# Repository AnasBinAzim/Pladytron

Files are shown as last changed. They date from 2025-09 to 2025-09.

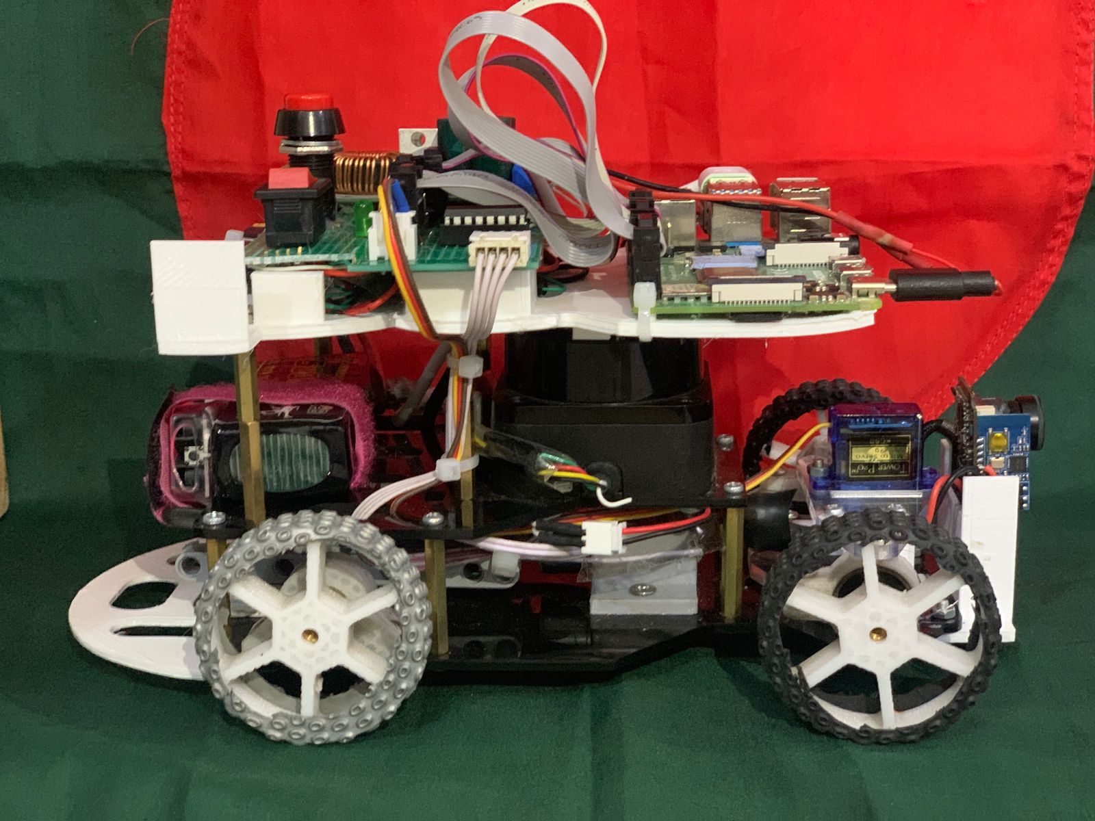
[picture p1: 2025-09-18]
v-photos/rightimage.jpeg

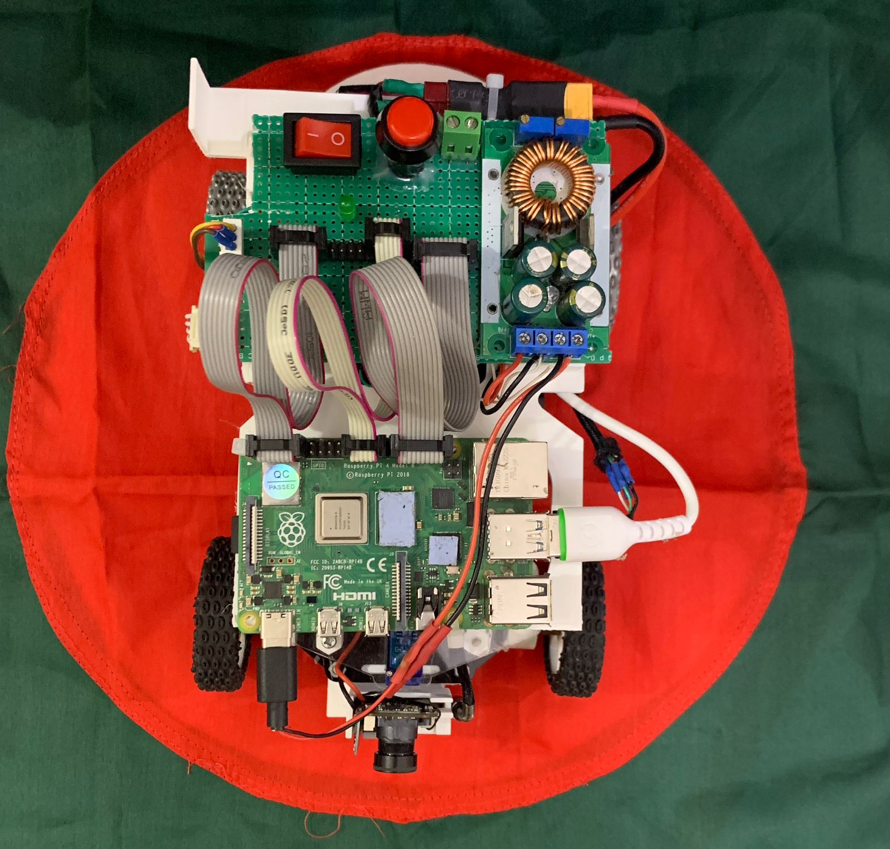
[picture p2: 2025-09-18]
v-photos/topimage.jpeg

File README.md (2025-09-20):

# **🤖 INTRODUCING TEAM PLADYTRON - WRO 2025**
<div align="center">
  

</div>

## 👥 **Team PLADYTRON**

| 👤 Name | 🎓 Institution | 📚 Class/Year | 🎂 Age  |
|---|---|---|---|
| **Anas Bin Azim** | Adamjee Cantonment College | Class XII | 17 |
| **SM Mohiuddin Sami**| Rajuk Uttara Model College | Class XII | 17 |

---

**Team Origin**: Bangladesh

---

## 🏅 Achievements

- 🥇 **Champion, WRO Bangladesh 2024 (Future Engineers)**
- 🌍 20th place **WRO International in Izmir, Turkey**
- 🛠 Multiple national awards in robotics, AI, and competitive programming contests

---

### 🌟 **The Meaning Behind PLADYTRON**

Our team, “PLADYTRON,” is a perfect blend of technology and imagination—think of Ultron if he had a heart (and wasn’t trying to destroy the world). Inspired by the advanced intelligence of Ultron, we aim to create something truly powerful—but with a lot less existential dread and world domination plans. Plady, on the other hand, is our grounding force, a reminder that even in the world of high-tech innovation, we still know how to laugh, learn, and—let's be honest—mess up a few things along the way.
Behind every project, every line of code, there’s an unseen force—kind of like a secret weapon. And that weapon? The unwavering support of those who stand with us. Their belief in us, quietly powering every step, is the real secret sauce to our success. It’s like having a sidekick in a superhero movie, except instead of a cape, they offer advice, encouragement, and the occasional snack.
Pladytron isn’t just a name—it’s the heart and humor of a shared dream. It’s a place where creativity meets technology, and where the unexpected becomes possible. We’re not just building robots or software—we’re building something that (hopefully) makes the world a little better and a lot more fun. After all, even Ultron had a good idea at first, right?

---

# The Team  

## Anas Bin Azim  



**Age:** 17  

**High School:** Adamjee Cantonment College, Dhaka 

**Description:** Hi! I’m Anas from Bangladesh and this is my second WRO International season. In 2024, I had the honor of representing Team Mayerdoa Robotics at the World Robot Olympiad in Turkey, where we proudly placed 20th in the Future Engineers category. I’ve been deeply involved in robotics for over 4 years, building autonomous systems and competing in both national and international competitions. Beyond robotics, I’m passionate about programming, innovation, quizzing, traveling, and playing cricket]  

---

## Mohiuddin Sami  



**Age:** 17  

**High School:** Rajuk Uttara Model College, Dhaka 

**Description:** Hi! I’m Sayed Md. Mohiuddin Sami from Rajuk Uttara Model College. I’ve been part of the BDOI camp for 2 years and have spent the last 2 years working in robotics and WRO. In 2024, I had the chance to represent Bangladesh at the World Robot Olympiad International Finals in Turkey. I’ve also been doing competitive programming for 4 years, which has helped me grow in problem-solving and logical thinking. Outside of robotics and coding, I enjoy quizzing, traveling, and exploring new ideas.

## 🎉 Project Overview
SMOKI

This repository includes all files, designs, and code for **SMOKI**, our WRO 2024 robot. Below is the folder structure:
Here’s a breakdown of the project folders:

---

## 📑 Table of Contents

- [Code](./Code)  
- [Software Setup](./Software-Setup)  
- [WRO 2024 Future Engineers: Self-Driving Project](./WRO-2024-Future-Engineers-Self-Driving...)  
- [Experiments](./experiments)  
- [Model](./model)  
- [Problems and Solutions](./problemsandsolutions)  
- [Schematic](./schematic)  
- [Source (src)](./src)  
- [t-photos](./t-photos)  
- [v-photos](./v-photos)  
- [Video](./video)  
- [README.md](./README.md)  
---

## Robot Photos (All Directions)

<table>
  <tr>
    <td align="center"><b>Front</b></td>
    <td align="center"><b>Back</b></td>
  </tr>
  <tr>
    <td>
</td>
    <td>
</td>
  </tr>
  <tr>
    <td align="center"><b>Top</b></td>
    <td align="center"><b>Bottom</b></td>
  </tr>
  <tr>
    <td>
</td>
    <td>
</td>
  </tr>
  <tr>
    <td align="center"><b>Left</b></td>
    <td align="center"><b>Right</b></td>
  </tr>
  <tr>
    <td>
</td>
    <td>
</td>
  </tr>
</table>

----

---

### Mission Overview for WRO Future Engineers Rounds

<table>
  <tr>
    <td width="50%" valign="top" align="left">
      <h3>🏁 Round 1: Lap Completion</h3>
      <p>In <strong>Round 1</strong>, the robot must autonomously complete <strong>three laps</strong> on a pre-defined track. The goal of this round is for the bot to demonstrate stable navigation and precise lap tracking without any obstacle avoidance requirements.</p>
      <ul>
        <li><strong>Objective</strong>: Complete three laps on the track within the allotted time.</li>
        <li><strong>Key Tasks</strong>: Accurate path-following, speed control, and lap counting.</li>
      </ul>
      <div align="center">
        <br><br><br><br><br>
        Round 1 WRO Track
      </div>
    </td>
    <td width="50%" valign="top" align="left">
      <h3>🏆 Round 2: Lap Completion with Obstacle Avoidance and Parking</h3>
      <p>In <strong>Round 2</strong>, the bot must complete <strong>three laps</strong> while avoiding green and red obstacles:</p>
      <ul>
        <li><strong>Green Obstacles</strong>: The bot should move <strong>left</strong> to avoid.</li>
        <li><strong>Red Obstacles</strong>: The bot should move <strong>right</strong> to avoid.</li>
      </ul>
      <p>After completing the laps, the bot must accurately park within a designated zone.</p>
      <ul>
        <li><strong>Objective</strong>: Complete three laps, avoid obstacles, and park in the designated area.</li>
        <li><strong>Tasks</strong>: Obstacle detection, color-based avoidance, and precision parking.</li>
      </ul>
      <div align="center">
        Round 2 WRO Track
      </div>
    </td>
  </tr>
</table>

---
>[!IMPORTANT]
>**Important: WRO Future Engineers Rulebook**
>* **Thorough Reading:** Ensure that you thoroughly read the **WRO Future Engineers 2024 Rulebook** to understand all rules and guidelines.
>* **Official Link:** Access the rulebook here: [🔗 WRO Future Engineers 2024 Rulebook](https://wro-association.org/competitions/future-engineers/).

---
---

## 🧩 Components and Hardware
Our bot is equipped with various components that support its autonomous functionality. Here is a breakdown of the key hardware elements used in this project:

| Component | Description | Image | Purchase Link |
|---|---|---|---|
| **Chassis - Custom Made** | Custom-designed chassis tailored to fit all components and optimize stability and movement. |  | N/A |
| **RPLIDAR C1** | 360-degree laser scanner used for mapping and obstacle detection. |  | [Purchase RPLIDAR C1](https://www.mybotshop.de/SLAMTEC-RPLIDAR-C1-360-Laser-Scanner-12-m) |
| **Servo Motor SG90** | Small, lightweight servo motor used for precise control of angles and positioning. |  | [Purchase SG90](https://bongotech.ai/product/sg90-micro-servo-motor-180-degree) |
| **SJ CAM C200** | Captures visual data, supporting navigation and obstacle detection tasks. |  | [Purchase SJ CAM C200](https://amzn.to/3SJCAM) (From previous knowledge) |
| **Buck Module XL4016** | Provides stable voltage regulation for power management. |  | [Purchase XL4016](https://amzn.to/4xl4016) (From previous knowledge) |
| **Motor Driver L293D** | Dual H-Bridge motor driver for controlling DC motors and stepper motors. |  | [Purchase L293D](https://electropeak.com/l293d-motor-drive-shield) |
| **Booster Module 5V to 40V** | Voltage booster module to step up power supply from 5V to 40V, supporting high-voltage requirements. |  | [Purchase Booster Module](https://robu.in/product-category/electronic-modules/electronic-module/buck-boost-converter/boost-converter/) |

# Mobility Management :

#### 🛠️ Chassis Assembly Process

## CHASSIS FIRST FLOOR : 



This is the first floor of the robot chassis, designed to serve as the primary structural layer of the bot. The STL model shows a flat base plate with multiple precisely positioned mounting holes and slots for components.

Key Features:

Steering Shaft Mount: The elongated slot at the top center is designed to hold the steering shaft, ensuring smooth and stable movement.

Servo Motor Mount: Dedicated mounting holes allow the servo motor to be securely attached for steering control.

Camera Holder: The central cut-out and surrounding structure provide space for installing a camera for vision-based navigation.

Wheel Mounts: Side holes are aligned to support the wheels, making them properly fixed to the frame.

Base Support: This floor acts as the foundation of the robot, supporting the upper floors and ensuring stability during operation.

Dimensions:

Width (X): 101.5 mm

Length (Y): 185.0 mm

Thickness (Z): 10.0 mm

---
---

### CHASSIS STEERING :


This is the steering plate of the robot chassis, designed to integrate with the first floor and provide precise steering control. The central rectangular gap is a servo clearance slot, which allows the servo horn and linkage to move freely during steering. The smaller holes around the center are meant for mounting the servo securely, while the larger side holes provide attachment points to connect the steering plate with the rest of the chassis. The plate is compact yet durable, ensuring stability during turns, and it directly connects the servo motor to the steering shaft and wheels, making it an essential component for controlling the robot’s movement.

Dimensions:

Width (X): 96.2 mm

Height (Y): 35.55 mm

Thickness (Z): 10 mm

---
---

### STEERING SHAFT :



This part is the steering shaft of the robot chassis. It connects directly to the steering plate and transmits the motion from the servo motor to the wheels, enabling controlled directional movement. The design includes a central body with mounting cut-outs and side holes that allow it to be fixed securely to the chassis while maintaining free rotational movement where needed. Its sturdy build ensures that torque from the servo is effectively transferred to the wheels without bending or slipping, making it a key component for precise steering.

Dimensions:

Width (X): 

Height (Y): 

Thickness (Z): 

---
---

## CHASSIS SECOND FLOOR :


This is the second floor of the robot chassis, designed to mount the following components:

RPLIDAR C1 (with a 10 cm clearance ensured by floor orientation)

LiPo 1500mAh 9A 3S battery

STL Dimensions: 131.27 mm × 101.50 mm × 10.00 mm

The plate includes cutouts for weight reduction and cable management, along with mounting holes for secure installation. Its orientation was carefully adjusted to provide the RPLIDAR with optimal clearance for unobstructed 360° scanning.

---

## CHASSIS TOP FLOOR:


Top & 3rd Floor – Electronics Section

This floor of the chassis holds the core electronic components required for power regulation and motor control.

Components

Raspberry Pi 4B – Acts as the main controller, handling computation, control logic, and communication.

XL4016 Buck Converter – Steps down the LiPo battery voltage to the levels required by the Raspberry Pi and other electronics.

L293D Motor Driver – Provides motor control by supplying the necessary current and voltage to the DC motors.

Power Switch – Allows safe shutdown and startup of the electronics.

Veroboard – Serves as the wiring platform, connecting the Raspberry Pi, buck converter, motor driver, and switch.

Functionality

The LiPo battery powers the system.

The buck converter regulates the voltage for stable Raspberry Pi operation.

The L293D motor driver interfaces between the Raspberry Pi and the motors, enabling directional control.

The veroboard ensures secure and organized wiring between all components.

The switch provides overall power control for the floor.

---
---

>[!IMPORTANT]
> ALL THE STL AND DXF FILES ARE PROVIDED IN THE MODEL SECTION AND A PREVIEW OF THE WHOLE THING COMBINED IS GIVEN BELOW.
---

# TOTAL PREVIEW:

## Model Views

<table>
  <tr>
    <td align="center"><b>Top</b></td>
    <td align="center"><b>Bottom</b></td>
  </tr>
  <tr>
    <td>rsz_iwo

</td>
    <td>bottomviewbot
</td>
  </tr>
  <tr>
    <td align="center"><b>Left</b></td>
    <td align="center"><b>Right</b></td>
  </tr>
  <tr>
    <td>leftviewbot
</td>
    <td>rightviewbot
</td>
<tr>
    <td align="center"><b>Tilt1</b></td>
    <td align="center"><b>Tilt2</b></td>
  </tr>
  <tr>
    <td>TILTEDIMAGE
</td>
    <td>TILTEDIMAGE

</td>
  </tr>

</table>

---
---

# Mobility Management:

The mobility system of our robot has been meticulously designed to ensure smooth, efficient, and reliable movement, addressing both power distribution and maneuverability. This section outlines the evolution of our robot's mobility systems, including upgrades to the steering and gear systems.

---

#### **16GA 800 RPM DC Gear Motor**

<table>
<tr>
<td width="50%">
<div align="center">
  

</div>
</td>
<td width="50%">

A **16GA DC gear motor** is a DC motor with an integrated gearbox. It provides controlled shaft rotation with increased output torque through gearbox reduction.

##### **How the Motor Works**
- The DC motor converts electrical input into rotational motion of the armature and shaft.  
- The gearbox stages reduce output speed and increase torque at the output shaft.  
- The D-flat on the shaft provides a positive mechanical interface for gears, pulleys, or couplings.

##### **Specifications**
- **Rated Speed:** 800 RPM  
- **Shaft Diameter:** 3.0 mm (D-flat: 2.5 mm)  
- **Gearbox Diameter:** 16 mm  
- **Gearbox Length:** 14 mm  
- **Motor Body Length:** 26.5 mm  
- **Shaft Length (protruding):** 11.2 mm

##### **Advantages**
1. **Compact Design**: Small gearbox diameter and short overall length for tight assemblies.  
2. **Increased Torque**: Gear reduction delivers higher torque at the output shaft for loaded conditions.  
3. **Positive Shaft Interface**: D-flat prevents rotary slip when fitted with set-screws or couplings.

</td>
</tr>
</table>

---

### **Rear Axle Power Distribution**

Initially, the rear wheels were powered through a **Bevel Gear**, but we later upgraded to a **Differential Gearbox** to improve efficiency and performance during turns.

---

#### **Bevel Gear**

<table>
<tr>
<td width="50%">
<div align="center">
  
</div>
</td>
<td width="50%">

A **bevel gear** is a type of gear where the axes of the two shafts intersect, and the tooth-bearing faces of the gears are conical. Bevel gears are commonly used to transfer motion between intersecting shafts at an angle, typically 90°.

##### **How Bevel Gears Work**
- A driver gear transfers motion to a driven gear, which rotates an output shaft.
- The teeth of the gears are designed to mesh smoothly, transferring torque efficiently between the shafts.

##### **Advantages of Bevel Gears**
1. **Compact Design**: Suitable for space-constrained applications.
2. **Efficient Torque Transfer**: Provides reliable power transmission at angles.
3. **Versatility**: Can operate at angles other than 90° if needed.

</td>
</tr>
</table>

---
>[!IMPORTANT]
> Bevel gears were essential in the initial stages of our design, but they had limitations in terms of energy efficiency during turns.
---

#### **Differential Gearbox**

<table>
<tr>
<td width="50%">

A **differential gearbox** allows the wheels on the same axle to rotate at different speeds while receiving power from a single motor. This is crucial for smooth turning, where the outer wheel must travel a larger distance than the inner wheel.

##### **Advantages of Differential Gearbox**
1. **Smooth Turns**: Adapts to varying wheel speeds, ensuring efficient cornering.
2. **Energy Efficiency**: Reduces energy wastage by minimizing wheel slippage.
3. **Component Longevity**: Minimizes wear on tires and axles.

##### **How Differential Gears Work**
- Power from the motor is delivered to an input shaft.
- The differential splits the torque between the two wheels via bevel or spider gears inside the housing.
- During turns, the differential allows one wheel to spin faster than the other, ensuring smooth movement.

</td>
<td width="50%">
<div align="center">
  
</div>
</td>
</tr>
</table>

---

### **Servo Motor with L293D Motor Driver**

<table>
<tr>
<td width="30%">
<div align="center">
  
</div>
</td>
<td width="70%">

We used the **L293D Motor Driver** in combination with a **Servo Motor** to control the robot's wheels effectively. The L293D is a dual H-Bridge motor driver that is perfectly suited for the LEGO motor, which operates at **750mA** current.

##### **Why L293D?**
- **Optimal Current Capacity**: Can handle up to **1A** peak current, suitable for the LEGO motor’s 750mA requirement.
- **Bidirectional Control**: Facilitates forward and backward motion of the wheels.
- **Compact and Lightweight**: Ideal for small-scale robotic systems.
- **PWM Support**: Enables smooth speed control of the motors.

##### **Advantages of the Servo Motor with L293D**
1. **Accurate Steering**: The servo motor ensures precise angle adjustments.
2. **Smooth Speed Control**: PWM functionality provides variable speed control.
3. **Efficient Current Management**: Matches the LEGO motor's current needs, ensuring reliable operation.

</td>
</tr>
</table>

---

#### **Comparison: Bevel Gear vs. Differential Gearbox**

| **Feature** | **Bevel Gear** | **Differential Gearbox** |
|---|---|---|
| **Turning Efficiency** | Limited; fixed wheel speeds. | Superior; wheels rotate independently. |
| **Energy Usage** | Higher due to slippage during turns. | Lower; optimized for dynamic turns. |
| **Durability** | Higher strain on components. | Reduced strain; longer component life. |

---

### **Steering Systems**

The robot was first designed with an Ackermann Steering System, which is widely recognized for its efficiency in full-scale vehicles where smooth and realistic cornering is important. This system was chosen because it closely replicates how cars steer, making it ideal for projects that aim to simulate real-world vehicle dynamics. However, as the design of the robot progressed, the steering system was later replaced with a LEGO-based steering mechanism. The change was made to simplify construction, reduce complexity, and improve modularity, all while maintaining effective and reliable steering control. The LEGO steering setup makes it easier to experiment, repair, and scale the design without sacrificing too much performance, which is an important advantage in prototyping and educational robotics.

The Ackermann Steering System itself is a clever mechanical arrangement that ensures each wheel follows a natural path while the vehicle turns. In any cornering situation, the inner wheels of a vehicle must rotate at a sharper angle than the outer wheels because they travel along a smaller radius. Without this adjustment, wheels would slip or drag, leading to wasted energy and uneven motion. The Ackermann geometry solves this by connecting the front wheels through steering arms angled in such a way that the imaginary extension of these arms intersects at the center of the turn’s radius. This alignment ensures that all wheels follow concentric paths, allowing the vehicle to turn smoothly and efficiently without excessive tire wear or unnecessary power loss.

In practice, the Ackermann system has several clear advantages for robotic applications. It minimizes slippage between the wheels and the ground, which results in more efficient turning and better energy conservation. The reduction of wheel drag also means that the motors driving the vehicle consume less power during maneuvers, which is especially valuable in battery-powered robots where energy efficiency extends operating time. Another key benefit is that it provides a highly realistic simulation of how cars steer, making it particularly useful for robotics projects that aim to mimic real-world automotive systems or serve as educational platforms to demonstrate fundamental vehicle dynamics. Although our project ultimately transitioned to a LEGO-based steering approach for modularity and ease of construction, the principles and advantages of Ackermann steering remain highly relevant for anyone interested in understanding efficient and practical steering systems in robotics and beyond.

---
---

## **SERVO MOTOR :** 
# Servo Motor - Tower Pro MG90S

<table>
  <tr>
    <td>
      
    </td>
    <td>
      <h3>Specifications</h3>
      <ul>
        <li><strong>Weight:</strong> 13.4g</li>
        <li><strong>Stall torque:</strong> 2.2 kgf·cm (6V)</li>
        <li><strong>Operating speed:</strong> 0.08 s/60° (6V)</li>
        <li><strong>Rotation angle:</strong> 120°</li>
        <li><strong>Gear type:</strong> Metal gears</li>
        <li><strong>Operating voltage:</strong> 4.8V – 6V</li>
      </ul>
    </td>
  </tr>
</table>

---

The Tower Pro MG90S is a micro servo motor designed for applications where compact size and high torque are required, making it a reliable choice for robotics, RC models, and automation projects. Built with durable metal gears, it offers a longer operational lifespan compared to plastic-geared alternatives, while maintaining a lightweight 13.4g profile that makes it easy to integrate into small-scale designs. Operating on a voltage range of 4.8V to 6V, it delivers up to 2.2 kgf·cm stall torque and a quick 0.08s/60° response at 6V, ensuring both strength and speed for demanding tasks. With a rotation range of 120°, the MG90S provides precise angular control suitable for robotic arms, pan-tilt camera gimbals, or steering systems in miniature vehicles. Its compatibility with standard PWM signals means it can be driven directly by most microcontrollers, including Arduino and Raspberry Pi, without the need for additional hardware. Engineers and hobbyists often choose the MG90S because it balances performance and durability in a very small form factor, making it a practical and cost-effective solution for projects that require accurate movement and dependable performance under continuous load.

---

## Where to Buy

You can purchase the servo motor here:  
👉 [Tower Pro MG90S - Cleste.ro](https://cleste.ro/motor-servo-mg90s-180g.html)

## SERVO-HOLDER :



### SG90 / MG90 Servo Holder

This is a **servo motor holder/mount** designed for **SG90** and **MG90S micro servos**.  
It provides a secure and stable way to fix the servo motor onto different surfaces such as a robot chassis, acrylic base, or wooden frame.

---

## Description
## Servo Motor Holder / Mount (SG90 & MG90S)

This servo motor holder is designed specifically for the popular SG90 and MG90S micro servos, providing a secure and reliable way to mount the motor onto different surfaces such as a robot chassis, acrylic base, or even wooden frames. The primary goal of the mount is to eliminate instability and vibration, ensuring that the servo can deliver accurate and repeatable movements during operation. For small-scale robotics and automation projects where precision matters, this holder becomes an essential accessory.
The base of the mount is a flat rectangular plate equipped with four mounting holes that allow it to be firmly attached using screws or bolts. This rigid foundation ensures that once the holder is installed, it remains stable and does not shift under load, even when the servo is driving linkages or mechanical arms. At the center of the design, there is a servo housing slot carefully dimensioned to snugly fit SG90 and MG90S servos. This slot prevents any side-to-side play and keeps the servo perfectly aligned, which is important when the servo is used for steering mechanisms, grippers, or robotic arms where accuracy of angular motion is critical.
On the sides of the housing are clamp sections with additional screw holes, which allow the servo to be tightly locked in place once inserted. This design makes sure the servo remains fixed during continuous operation, preventing unwanted movement that could lead to mechanical inaccuracy or wear. At the front, the mount features an open clearance space that allows the servo horn or arm to rotate freely without obstruction. This ensures that the servo’s full range of motion can be utilized, whether it is controlling wheels, levers, or pan-tilt systems.

The bottom of the mount is left open to provide space for the servo’s wiring to pass through. This prevents cable bending and stress at the connector, reducing the risk of damage to the wires over time and allowing easy integration into compact robotic builds. By providing both mechanical stability and practical cable management, the holder is designed to extend the lifespan of the servo and improve overall reliability of the system.

In terms of material, PLA is often sufficient for hobby projects where light loads and indoor conditions are expected. However, for applications requiring greater durability or exposure to outdoor environments, PETG or ABS is recommended since both materials offer improved toughness and resistance to stress compared to PLA. The mount’s design is fully compatible with Tower Pro SG90 and MG90S servos, making it versatile for use across a wide range of robotic and automation projects where these micro servos are commonly deployed.

---
---
# ⚡ Power and Sense Management

The **Power and Sense Management** system of our robot has been meticulously designed to optimize performance while ensuring reliable power delivery, precise sensing, and efficient communication between components.
# Battery: Gens Ace Airsoft 3S Li-Po Battery (11.1V 1500mAh 35C)

<table>
  <tr>
    <td>
      
    </td>
    <td>
      <h3>Specifications</h3>
      <ul>
        <li><strong>Brand:</strong> Gens Ace Airsoft</li>
        <li><strong>Battery Type:</strong> Li-Po (Lithium Polymer)</li>
        <li><strong>Nominal Voltage:</strong> 11.1V (3S)</li>
        <li><strong>Capacity:</strong> 1500 mAh</li>
        <li><strong>Energy:</strong> 16.65 Wh</li>
        <li><strong>Discharge Rate:</strong> 35C</li>
        <li><strong>Connector Type:</strong> T-Plug / Deans Connector</li>
        <li><strong>Balance Plug:</strong> JST-XH</li>
        <li><strong>Weight:</strong> ~120g</li>
      </ul>
    </td>
  </tr>
</table>

---

The **Gens Ace 3S Li-Po battery** is a lightweight and powerful energy source designed for high-performance robotics, drones, RC vehicles, and airsoft equipment.  
With a **capacity of 1500mAh** and a **35C discharge rating**, it delivers consistent current output suitable for motors, sensors, and controllers that require stable power.  
Its **compact size and low weight** make it easy to integrate into mobile robotic platforms.  
The built-in **Deans/T-Plug connector** ensures low-resistance power delivery, while the **JST-XH balance connector** allows for safe charging and cell balancing.  

This battery is ideal for applications requiring **high burst currents, reliability, and long cycle life**, making it a solid choice for powering small-to-medium robotics systems.

---

# **Microcontroller :**  
# Raspberry Pi 4 Model B

<table>
  <tr>
    <td>
      
    </td>
    <td>
      <h3>Specifications</h3>
      <ul>
        <li><strong>Processor:</strong> Broadcom BCM2711, Quad-core Cortex-A72 (ARM v8) 64-bit SoC @ 1.5GHz</li>
        <li><strong>RAM Options:</strong> 2GB, 4GB, or 8GB LPDDR4-3200 SDRAM</li>
        <li><strong>Networking:</strong> Gigabit Ethernet, 2.4GHz & 5.0GHz 802.11ac Wi-Fi, Bluetooth 5.0</li>
        <li><strong>USB Ports:</strong> 2 × USB 3.0, 2 × USB 2.0</li>
        <li><strong>Video & Sound:</strong> 2 × micro-HDMI ports (up to 4Kp60), MIPI DSI display port, MIPI CSI camera port</li>
        <li><strong>Storage:</strong> microSD card slot for OS and data storage</li>
        <li><strong>GPIO:</strong> 40-pin header, backward-compatible with previous Raspberry Pi boards</li>
        <li><strong>Power:</strong> 5V DC via USB-C connector (minimum 3A)</li>
        <li><strong>Dimensions:</strong> 85.6mm × 56.5mm</li>
      </ul>
    </td>
  </tr>
</table>

---

The **Raspberry Pi 4 Model B** is a powerful single-board computer that serves as the main controller of the robot.  
It offers significant improvements over previous models, including a faster **quad-core ARM Cortex-A72 CPU**, more memory options, dual micro-HDMI outputs supporting **dual 4K displays**, and faster networking with **true Gigabit Ethernet** and **dual-band Wi-Fi**.  
Its 40-pin GPIO header provides compatibility with a wide range of sensors, motor drivers, and other modules, making it extremely versatile for robotics and IoT applications.  

Thanks to its **USB 3.0 ports**, it can interface with high-speed peripherals such as cameras, LIDAR sensors, or external storage, while the **USB-C power input** ensures stable operation.  
In this project, the Raspberry Pi 4B acts as the **central brain**, handling computer vision, path planning, and high-level decision-making, while coordinating with microcontrollers, sensors, and actuators to control the entire robot.

---

## **GPIO PINOUT OF RPI 4B** : 

# Raspberry Pi 4 Model B GPIO (40-pin Header)

<table>
  <tr>
    <td>
      
    </td>
    <td>
      <h3>Specifications</h3>
      <ul>
        <li><strong>Total Pins:</strong> 40 (2×20 header)</li>
        <li><strong>Power Pins:</strong> 2 × 5V, 2 × 3.3V, 8 × Ground (GND)</li>
        <li><strong>GPIO Pins:</strong> 26 (configurable as input/output)</li>
        <li><strong>Dedicated Interfaces:</strong> 
          <ul>
            <li>UART (TXD, RXD)</li>
            <li>SPI (MOSI, MISO, SCLK, CE0, CE1)</li>
            <li>I²C (SDA, SCL)</li>
            <li>PWM channels</li>
          </ul>
        </li>
        <li><strong>Voltage Levels:</strong> 3.3V logic (NOT 5V-tolerant)</li>
        <li><strong>Backward Compatibility:</strong> Same pinout as Raspberry Pi 3B/3B+</li>
      </ul>
    </td>
  </tr>
</table>

---

The **Raspberry Pi 4B GPIO header** provides 40 pins that allow direct hardware interfacing with sensors, actuators, and external modules.  
Among these are multiple **power pins (5V and 3.3V)**, **ground pins**, and **26 flexible GPIO pins** which can be programmed as input or output using libraries such as **RPi.GPIO** or **GPIO Zero**.  

The header also exposes dedicated hardware interfaces, including **UART for serial communication**, **SPI for high-speed device connections**, and **I²C for multi-sensor integration**, along with PWM support for driving **motors, LEDs, and servos**.  

Because the pins operate at **3.3V logic levels**, external level shifters are required when interfacing with 5V components.  
This GPIO header is the bridge between the Raspberry Pi and the physical world, making it an essential feature for robotics, IoT, and embedded system projects.

---
---

## **BUCK CONVERTER** (8.4 TO 5V) : 
### XL4016 DC-DC Step-Down Module

<table>
  <tr>
    <td>
      
    </td>
    <td>
      <h3>Specifications</h3>
      <ul>
        <li><strong>Chipset:</strong> XL4016E1 DC-DC Buck Converter</li>
        <li><strong>Input Voltage:</strong> 8V – 36V DC</li>
        <li><strong>Output Voltage:</strong> 1.25V – 32V DC (adjustable)</li>
        <li><strong>Output Current:</strong> Up to 8A (continuous), 12A peak</li>
        <li><strong>Conversion Efficiency:</strong> Up to 95%</li>
        <li><strong>Switching Frequency:</strong> ~180 kHz</li>
        <li><strong>Protections:</strong> Over-current, thermal shutdown</li>
        <li><strong>Heat Dissipation:</strong> Integrated heatsink for stability under high load</li>
        <li><strong>Dimensions:</strong> 60mm × 52mm × 20mm (approx.)</li>
      </ul>
    </td>
  </tr>
</table>

---

The **XL4016 buck converter** is a high-power DC–DC step-down module designed to provide stable and efficient voltage regulation for robotics, automation, and embedded systems. With an input range of 8–36V and an adjustable output from 1.25–32V, it is highly versatile and can power a wide variety of subsystems from a single battery source. Its ability to deliver up to **8A of continuous current** (with peaks of 12A) makes it suitable for driving motor controllers, Raspberry Pi boards, and other current-hungry electronics simultaneously. The module achieves up to 95% efficiency, reducing energy losses and minimizing heat buildup. The integrated heatsink ensures stable operation even under heavy loads, while built-in protection circuits safeguard against over-current and thermal issues. For robotics applications, the XL4016 is often recommended because it allows a single Li-Po or Li-ion battery pack to be safely stepped down to multiple regulated voltages, ensuring reliable operation of both logic-level electronics and power-hungry actuators.

---

## **Sensor :**  
# MPU-6050 6-Axis Gyroscope and Accelerometer

<table>
  <tr>
    <td>
      
    </td>
    <td>
      <h3>Specifications</h3>
      <ul>
        <li><strong>Chipset:</strong> InvenSense MPU-6050</li>
        <li><strong>Sensor Type:</strong> 3-axis gyroscope + 3-axis accelerometer</li>
        <li><strong>Operating Voltage:</strong> 3V – 5V</li>
        <li><strong>Communication Interface:</strong> I²C (default address 0x68)</li>
        <li><strong>Gyroscope Range:</strong> ±250, ±500, ±1000, ±2000 °/s</li>
        <li><strong>Accelerometer Range:</strong> ±2g, ±4g, ±8g, ±16g</li>
        <li><strong>Sampling Rate:</strong> Up to 1 kHz</li>
        <li><strong>Digital Motion Processor (DMP):</strong> Built-in for sensor fusion</li>
        <li><strong>Dimensions:</strong> ~20mm × 15mm × 2mm (module size varies)</li>
      </ul>
    </td>
  </tr>
</table>

---

The **MPU-6050** is a 6-axis motion tracking sensor that integrates a **3-axis gyroscope** and a **3-axis accelerometer** on a single chip, making it one of the most widely used sensors in robotics and embedded systems. It communicates via the I²C protocol, which allows it to connect easily to microcontrollers like the Arduino, ESP32, or Raspberry Pi. The sensor provides motion data across multiple selectable ranges, with gyroscope sensitivity from ±250 to ±2000 degrees per second and accelerometer ranges from ±2g to ±16g. This versatility makes it suitable for detecting orientation, angular velocity, and linear acceleration in real time. The built-in **Digital Motion Processor (DMP)** can handle sensor fusion internally, combining gyro and accelerometer data to output stable orientation values, reducing the computational load on the main controller. For robotics, the MPU-6050 is commonly used in balancing robots, drones, navigation systems, and motion-controlled projects, where accurate and responsive motion sensing is essential for stability and control.

---

## **Camera :**  
# SJCAM C200 Action Camera

<table>
  <tr>
    <td>
      
    </td>
    <td>
      <h3>Specifications</h3>
      <ul>
        <li><strong>Sensor:</strong> 4K CMOS image sensor</li>
        <li><strong>Video Resolution:</strong> 4K @ 24fps, 2K @ 30fps, 1080p @ 60fps</li>
        <li><strong>Photo Resolution:</strong> Up to 16MP</li>
        <li><strong>Lens:</strong> 154° wide-angle lens</li>
        <li><strong>Display:</strong> 1.3-inch front screen + status indicators</li>
        <li><strong>Battery:</strong> 1200mAh (removable, USB-C charging)</li>
        <li><strong>Connectivity:</strong> Wi-Fi, USB-C</li>
        <li><strong>Storage:</strong> MicroSD card up to 128GB</li>
        <li><strong>Waterproof:</strong> Up to 5m without case, 30m with case</li>
        <li><strong>Dimensions:</strong> ~68mm × 32mm × 26mm</li>
      </ul>
    </td>
  </tr>
</table>

---

The **SJCAM C200** is a compact 4K action camera designed for high-quality video and photo capture in robotics, drones, and field-testing environments. It features a **154° wide-angle lens**, making it well-suited for wide field-of-view applications such as navigation, mapping, and vision-based obstacle detection. The camera supports recording at multiple resolutions, including **4K at 24fps** and **1080p at 60fps**, giving flexibility between image detail and frame rate depending on the task. With a removable **1200mAh battery** and **USB-C charging**, it provides convenient power management, while Wi-Fi connectivity allows real-time preview and data transfer to companion devices. Its rugged design makes it waterproof up to 5m without housing and up to 30m with an additional case, ensuring reliable performance in outdoor and challenging environments. For robotics projects, the SJCAM C200 is an excellent choice as a vision module, balancing portability, durability, and high-definition imaging in a small and versatile package.
---
---

# *PCB*  
## Previous PCB Design and Power Distribution  

| **Top View of PCB** | **Bottom View of PCB** | **Power Management Diagram** |
|---|---|---|
|  |  |  |

---

The PCB shown above was designed as the **central power management and distribution unit** for the robot, ensuring that every subsystem received the correct voltage and current for stable operation. The board draws power from two **Lithium-Ion cells**, each rated at 4.2V, providing a combined supply of **8.4V** when fully charged. This input is then carefully regulated using multiple DC–DC converters to meet the diverse requirements of the system.  

At the heart of the regulation stage, an **XL4016 buck converter** steps the 8.4V battery voltage down to a stable **5V rail**, which powers the **Raspberry Pi 5** and other core electronics. Additional buck converter modules are integrated to provide subsystem-specific voltages: one module regulates to **6V for the servo motor**, while another supplies **5V dedicated to the ESP32 microcontroller**, ensuring isolation and consistent operation. For the high-power motors, the PCB incorporates a **buck-boost converter** that outputs **12V**, guaranteeing reliable torque and speed even as the battery voltage drops during operation.  

This combination of regulated rails allows the robot to operate multiple controllers, sensors, and actuators from a single compact PCB without instability or power loss. By integrating switching converters and carefully routing the distribution, the board minimizes heat, maximizes efficiency, and protects sensitive comp
onents from voltage fluctuations. Overall, this design highlights the importance of structured power management in robotics, where both logic-level devices and power-hungry actuators must coexist seamlessly on the same platform.

---
# *CurrentPCB* :


Compared to our earlier design, the new PCB introduces several improvements aimed at stability, modularity, and ease of use. The earlier version primarily served as a basic power distribution board with buck converters and minimal control features. In this revised version, additional attention has been given to **structured wiring via ribbon connectors**, improved **switching and manual control through a larger rocker and push button**, and **better integration of the buck converter section** with heat dissipation. The placement of capacitors, inductor coil, and screw terminals has been optimized for cleaner power flow, and the routing now reduces noise and voltage drops across the board. Overall, the new design is more robust, reliable, and serviceable compared to the prototype.  

# *CIRCUITDIAGRAM* :


# Explanation:

This circuit integrates the Raspberry Pi GPIO header with a set of sensors, actuators, and motor driver modules, forming the control and power distribution system for a small robot. The Raspberry Pi acts as the central controller, sending signals to motors, servos, and indicators while also receiving sensor feedback to make decisions in real time.
At the top of the diagram, we see the Raspberry Pi GPIO pinout, which is the core interface between the Pi and external devices. Each pin can be configured as an input or output, supplying logic-level signals (3.3V) that control the connected hardware. The Pi provides 5V and 3.3V power rails, as well as ground connections, which are distributed to all modules in the circuit.
A servo motor is connected to the Pi using three wires: VCC (power), GND (ground), and the SIGNAL pin, which is linked to one of the Pi’s PWM-enabled GPIO pins. This allows the Pi to control the servo angle precisely using PWM (Pulse Width Modulation). Servos are typically used for steering mechanisms or angular adjustments in robots, so this one is likely managing the robot’s front wheel alignment or a pan/tilt system.
On the left side of the circuit, a push button and an LED are wired into the GPIO header. The push button is used as a digital input — when pressed, it connects the GPIO pin to ground, sending a low signal to the Pi. This can be used for resets, mode changes, or manual overrides. The LED, on the other hand, is controlled through a GPIO pin as an output. It provides visual feedback, such as power status, errors, or activity indicators, allowing the operator to easily monitor the robot’s state.
At the bottom, the L293D motor driver IC is connected between the Pi and a DC motor. The Pi itself cannot supply enough current to directly drive motors, so the L293D acts as a buffer and amplifier. It uses the low-current logic signals from the Pi to control the higher-current flow from the battery to the motor. This enables bidirectional motor control (forward and backward rotation) and also supports PWM for speed regulation. In this configuration, the motor shown is most likely one of the drive motors that moves the robot’s wheels.
On the right side, we see an MPU-6050 IMU (Inertial Measurement Unit) connected via I²C communication. The SDA (data) and SCL (clock) lines run from the Pi’s GPIO header to the sensor module, with VCC and GND providing power. The MPU-6050 combines a 3-axis gyroscope and a 3-axis accelerometer, which together measure angular velocity and linear acceleration. This data is essential for balance, orientation, and navigation, particularly in robots that need to track their motion or maintain stability on uneven terrain.
Next to it is a buck converter module (with a heatsink and inductor coil). This component regulates the battery voltage down to safe levels required by the Raspberry Pi, motors, and sensors. Since motors can cause voltage fluctuations when they start or stop, the buck converter ensures that the Pi always receives a clean and stable supply. The input of the buck converter comes directly from the main battery (Li-ion cells), and the outputs are distributed to different subsystems: 5V for the Pi and ESP32, 6V for the servo, and 12V (via buck-boost regulation) for the motors.
The wiring shows how all the power rails (red for positive, black for ground, and green/yellow/orange for signals) are carefully routed to prevent noise and maintain clear separation between logic-level signals and high-current motor wiring. The Pi orchestrates everything: it reads the sensor data from the MPU-6050, processes input from the push button, controls the LED for feedback, drives the servo motor with PWM, and commands the DC motor through the L293D motor driver.

---
# *SCHEMATIC FOR THE NERDS* : 


###  Camera Placement and Functionality

The robot's main camera is positioned at the top and angled slightly downwards. This setup enhances object detection capabilities by providing:
- **🔍 Close-Range Detection**: The camera can identify objects in close proximity with high accuracy.
- **🌐 Extended-Range Detection**: Ensures objects further away are detected effectively.

The camera feeds data to the **Raspberry Pi 4**, which processes image recognition algorithms to detect towers and corner lines. The processed data is then transmitted to the **ESP32 microcontroller** for real-time navigation and obstacle avoidance.

---

>[!IMPORTANT]
> **Power Highlights:**
> - The XL4016 Buck Converter ensures stable voltage regulation, critical for protecting the Raspberry Pi and ESP32 microcontroller during operation.
> - Independent buck modules handle the servo motor and ESP32 power needs, optimizing energy usage across all components.

---
---

## Power Regulation and Control PCB

This PCB is a custom-made prototyping board that acts as the main power regulation and control hub of the robot. It integrates a red rocker switch as the primary ON/OFF control, a large red push button for reset or emergency stop functions, and a green LED that indicates when the system is active. Flat ribbon cables connect the board to the Raspberry Pi or Arduino, carrying essential GPIO signals. The lower section features a copper coil, multiple electrolytic capacitors, and MOSFETs/regulators that form a DC–DC converter, ensuring stable power delivery from the battery to different subsystems. Blue trimpots allow precise voltage calibration, while a screw terminal block provides secure connections for input and output wiring. Altogether, this PCB manages distribution, stabilization, and manual control of power, making it a central part of the robot’s electronic system.

PCB Overview

---

#  OBSTACLE MANAGEMENT AND CODE EPXLANATION

In **Round 1**, our robot **SMOKI** must autonomously complete **three laps** on a predefined track without the need for obstacle avoidance. To achieve precise navigation and lap counting, we have developed a robust algorithm that integrates image processing with control systems.

---

###  Algorithm Overview

1. **📸 Image Acquisition**:
   - The robot captures real-time images of the track using its onboard camera.

2. **🎨 Color Space Conversion**:
   - Captured images are converted from the **RGB** color space to the **HSV (Hue, Saturation, Value)** color space.
   - The HSV color space is chosen for its effectiveness in color segmentation, as it is less sensitive to lighting variations.

3. **🔍 Color Segmentation and Orientation Determination**:
   - Using predetermined HSV ranges, the algorithm isolates the **blue** and **orange** line segments on the track.
   - During the first run, the robot checks whether the blue line appears before the orange line or vice versa.
   - **Orientation Determination**:
     - If the blue line comes before the orange line, the robot sets its orientation accordingly.
     - This initial orientation check ensures the robot follows the track in the correct direction.

4. **📏 Line Detection and Lap Counting**:
   - The **Hough Line Transform** method is applied to detect lines within the segmented images.
   - The robot counts the detected lines to keep track of laps.
   - **Lap Completion**:
     - After counting **12 lines** (corresponding to three laps), the robot initiates a predetermined delay and then stops.

5. **⚙️ Position Correction Using PID Control**:
   - Before setting the orientation, a **PID (Proportional-Integral-Derivative) controller** calculates the error.
   - **Error Calculation**:
     - The error is determined by the difference between the distances measured by sensors on the left and right sides of the robot (i.e., `error = left_distance - right_distance` or vice versa).
   - **Distance Maintenance**:
     - If the orientation is **right-based**, the robot maintains a **25 cm** distance from the right side.
     - If the orientation is **left-based**, it maintains a **25 cm** distance from the left side.
   - The PID controller adjusts the robot's steering to minimize the error, helping it stay centered on the track.

---

The process begins with image acquisition and preprocessing, where high-resolution images are captured at regular intervals to provide up-to-date visual data of the track. These images are then converted into the HSV (Hue, Saturation, Value) color space. Unlike RGB, HSV separates brightness from color information, which makes it more effective for thresholding and detecting specific colors under varying lighting conditions.
Once the images are converted, color segmentation is performed. By applying HSV thresholding, the system isolates pixels belonging to the blue and orange ranges. This allows the robot to detect both blue and orange track lines. The sequence of detected colors is also analyzed to establish the robot’s orientation at the start, ensuring it does not misinterpret direction and mistakenly count laps in reverse.
After segmentation, the system proceeds to line detection using the Hough Transform. First, preprocessing methods such as Gaussian blur and Canny edge detection are applied to enhance the visibility of edges in the image. The Hough Line Transform then detects straight lines by mapping points from image space into a parameter space, identifying lines where multiple points converge. Each detected line crossing increments a counter, and lap completion is recognized after twelve line crossings, which correspond to three full laps of both blue and orange lines combined.
To maintain correct alignment on the track, the robot employs a PID (Proportional–Integral–Derivative) control system for position correction. Distance sensors on either side of the robot provide real-time measurements of its relative position. The difference between left and right readings produces an error signal, which the PID controller minimizes. The proportional term reacts to the current error, the integral term compensates for accumulated past errors, and the derivative term predicts future error based on its rate of change. The controller’s output is translated into steering adjustments, keeping the robot centered. Depending on its orientation, the robot may also bias its movement slightly toward the left or right side of the track, ensuring consistent lap recognition and stable navigation.

## 📊 Round 1 Algorithm - Corner Detection Navigation

In Round 1 of the **Future Engineers** category, our robot follows a structured pipeline to complete a lap, detect corners, and terminate correctly at the finish line. The algorithm is designed to balance **robust line tracking** with **precise stopping conditions**.

---
# Explanation of the the first round :
The flowchart represents the logic behind a line-following robot with LIDAR support, where lap counting and orientation checks are integrated into its navigation system. Let’s walk through it in sequence.
1. Start and Image Capture
The process begins at the Start node. The robot immediately moves to capture an image from its camera. This image forms the basis for detecting whether the guiding line (blue or orange track line) is present in the current frame.
2. Checking for Line Detection
After capturing the image, the robot checks: Is a line detected?
If Yes, it proceeds to the orientation check.
If No, the robot relies on LIDAR scanning to infer the path instead.
This dual check ensures that if the camera fails to detect a line (due to noise, occlusion, or lighting issues), the LIDAR system provides redundancy.
3. Line Detected Path
If a line is found, the robot must determine whether its orientation has already been set.
If orientation is set, the system simply increments the line counter (Line Count ++), tracking how many lines have been crossed.
If orientation is not set, the robot fixes its orientation based on the detected color sequence (blue vs. orange) and also increments the line counter. This prevents mistakes in lap counting by ensuring the robot knows which direction it is traveling.
4. Lap Completion Check
Once the line count is updated, the system checks three conditions simultaneously:
LineCount ≥ 12 → meaning the robot has crossed enough lines for three full laps (each lap includes multiple blue/orange crossings).
LastLine > 1500 ms → a time gap condition that prevents double-counting if two detections happen too close together.
FloorDist < 1500 → a distance-based condition to ensure the robot is physically on the track surface and not falsely detecting lines elsewhere.
If all conditions are satisfied, the robot concludes that laps are complete, moves to Stop Bot, and terminates the code.
If not, the system moves to path correction with LIDAR and PID control.
5. No Line Detected Path
If the camera does not detect a line, the robot initiates a LIDAR scan of its surroundings. From this scan, it checks the slope of adjacent lines detected by LIDAR.
If the slope is perpendicular, this indicates the robot has crossed a track line, so the line counter is incremented and lap completion is re-evaluated.
If the slope is not perpendicular, the system assumes the robot is simply navigating without crossing a line and moves to LIDAR-based pathfinding.
This branch ensures the robot doesn’t lose track of lap progress even if the camera fails.
6. Weighted Average Pathfinding with LIDAR
When either:
the lap is not complete, or
no perpendicular crossing is found,
the system falls back to LIDAR-based navigation. Here, the robot uses a weighted average method from LIDAR readings to determine the best safe path forward (e.g., avoiding obstacles and staying centered).
7. PID Steering Correction
Once the best path is determined, the robot applies a PID controller to calculate the precise steering angle.
The error signal is generated from differences in left/right LIDAR (or distance sensor) readings.
The PID controller minimizes this error to keep the robot aligned on track.
8. Continuing Navigation
Finally, the robot applies the PID steering adjustment and continues navigating along the track until it loops back to capture the next image, repeating the cycle until the termination condition is met.
---
**Flowchart:**

```mermaid
flowchart TD
    A[Start] --> B[Capture Image]
    B --> C{Line Detected?}
    
    %% Line Detected Branch
    C -->|Yes| D{Orientation Set?}
    D -->|Yes| E[Line Count ++]
    D -->|No| F[Fix Orientation for Next Run and Line Count ++]
    E --> G{LineCount >= 12 AND LastLine > 1500ms AND FloorDist < 1500?}
    F --> G
    G -->|Yes| H[Stop Bot and Terminate Code]
    G -->|No| K[Use Weighted Average from LIDAR to Find Best Path]
    
    %% No Line Detected Branch
    C -->|No| I[LIDAR Scan Image]
    I --> J{Slope of Adjacent Lines?}
    J -->|Perpendicular| L[Line Count ++]
    J -->|Not Perpendicular| K
    L --> G
    
    %% Common Path
    K --> M[PID Calculates Steering Value]
    M --> N[Continue Navigation]

```

---

# CODE EXPLANATION :
## LIDAR CODE:


The LidarReader class provides a simple interface for capturing and storing LiDAR sensor data in real time during the robot’s first round of operation. When initialized, it starts an external LiDAR driver program as a subprocess, configured with a serial port and baud rate. A background thread continuously reads the sensor’s live output from the subprocess, line by line. Each line, containing an angle and a distance measurement, is parsed using a regular expression. The parsed results are stored in a dictionary where each angle (in degrees) is mapped to its corresponding distance value. This allows the robot to quickly access either the distance at a specific angle or retrieve all available readings at once. The stop() method cleanly terminates the subprocess when the LiDAR is no longer needed. Overall, this design ensures non-blocking, thread-safe data collection from the LiDAR, enabling the robot to maintain a constantly updated map of its surroundings during navigation.
---

## Line Checker Code:



# Geometric Line Operations

This repository contains a set of Python functions for performing geometric operations on lines. These functions are useful for tasks like checking if points lie on a straight line, determining if two lines are perpendicular, and finding the intersection of two lines. The operations rely on the `numpy`, `scipy`, and `shapely.geometry` libraries for numerical and geometric computations.

The functions include:

- **`coords(r, theta_deg)`**: Converts polar coordinates (radius `r` and angle `theta_deg` in degrees) into Cartesian coordinates (`x`, `y`). This is useful for converting data in polar form to standard Cartesian coordinates for easier geometric calculations.
  
- **`linearity(points)`**: This function checks if a set of points lies approximately on a straight line using linear regression. The function calculates the best-fit line using the `scipy.stats.linregress` function, returning a boolean indicating if the points are linear (based on an R-squared threshold), the slope and intercept of the line, and the R-squared value of the linear regression. It also handles the case of vertical lines (where all x-coordinates are the same).
  
- **`are_perpendicular(m1, m2)`**: This function checks whether two lines with slopes `m1` and `m2` are perpendicular. For two lines to be perpendicular, the product of their slopes should be `-1`. The function also handles special cases where one or both lines are vertical (undefined slopes), as vertical lines have unique behavior when checking perpendicularity.
  
- **`get_intersection(m0, b0, m1, b1)`**: Given two lines, the function computes their intersection point. The lines are represented by their slopes (`m0`, `m1`) and intercepts (`b0`, `b1`). If one of the lines is vertical (slope is `None`), the function calculates the intersection accordingly. Otherwise, the intersection is found using the formula for the intersection of two lines: solving for `x` and using the result to find `y`.

### Dependencies

The functions rely on the following Python libraries:
- `numpy`: For handling numerical operations such as trigonometry and arrays.
- `scipy`: Specifically, the `scipy.stats.linregress` function is used for performing linear regression and calculating the R-squared value.
- `shapely`: A library for geometric operations (though not directly used in the provided functions, it may be part of future implementations for geometry-related tasks).

# Motor Code :


This Python class is designed to control a motor's forward and reverse rotation using the `pigpio` library. It uses PWM (Pulse Width Modulation) to control the speed of the motor, and GPIO pins on the Raspberry Pi are used to drive the motor in either direction. The class provides three primary functions: **forward**, **reverse**, and **stop**.

## Dependencies

- `pigpio`: The `pigpio` library is used to interface with the GPIO pins of the Raspberry Pi. It allows us to control the motor's direction and speed using PWM signals.

- `utility`: This imports `clamp` (and optionally `map_range`) for ensuring the speed value remains within the appropriate range (0 to 255).

## Motor Class

### `__init__(self, pi, forward_pin=12, reverse_pin=18, freq=1000)`

This is the constructor of the `Motor` class. It initializes the motor control, including setting up the GPIO pins and the PWM frequency.

#### Parameters:
- `pi`: The `pigpio.pi()` instance (already connected to the Raspberry Pi).
- `forward_pin`: The GPIO pin number for controlling the forward direction of the motor (default is pin 12).
- `reverse_pin`: The GPIO pin number for controlling the reverse direction of the motor (default is pin 18).
- `freq`: The frequency for the PWM signal (default is 1000 Hz).

### `forward(self, speed=255)`

This function runs the motor in the forward direction at a specified speed. The speed is provided as a PWM duty cycle value ranging from 0 to 255.

#### Parameters:
- `speed`: The motor speed, represented as a PWM duty cycle value. The default value is 255 (maximum speed).

The function:
- Clamps the `speed` to ensure it is between 0 and 255.
- Sets the PWM frequency for the forward direction.
- Sets the duty cycle for the forward direction pin to control the speed.
- Ensures the reverse direction pin is turned off.

### `reverse(self, speed=255)`

This function runs the motor in the reverse direction at a specified speed. Like the `forward()` function, it uses a PWM duty cycle value between 0 and 255 to control speed.

#### Parameters:
- `speed`: The motor speed, represented as a PWM duty cycle value. The default value is 255 (maximum speed).

The function:
- Clamps the `speed` to ensure it is between 0 and 255.
- Sets the PWM frequency for the reverse direction.
- Sets the duty cycle for the reverse direction pin to control the speed.
- Ensures the forward direction pin is turned off.

### `stop(self)`

This function stops the motor completely by turning off both the forward and reverse direction pins. It sets the PWM duty cycle for both pins to 0, effectively stopping the motor.

#### Functionality:
- Sets the PWM duty cycle for both the forward and reverse pins to 0.
- Stops the motor in both directions.

---

# LIDAR READER CODE:


# LidarReader Class

This repository contains a Python class `LidarReader` designed to interface with a Lidar sensor connected via a serial port. It continuously reads data from the Lidar sensor and stores it in a dictionary, where the keys are angles and the values are the corresponding distances. The class runs the Lidar process in a background thread, ensuring non-blocking operation for continuous data reading.

## Overview

The `LidarReader` class is responsible for:
1. Launching an external Lidar binary as a subprocess.
2. Continuously reading and parsing the sensor's output (angle and distance data).
3. Storing the readings in a dictionary.
4. Providing methods to retrieve the Lidar data at specific angles or as a complete dataset.
5. Allowing the process to be terminated when no longer needed.

## Methods

### 1. `__init__(self, path, port="/dev/ttyUSB0", baud="460800")`
This is the constructor method that initializes the Lidar reader by:
- Starting the Lidar process as a subprocess.
- Setting up a background thread to continuously read and parse the Lidar output.

#### Parameters:
- `path` (str): The path to the Lidar binary (e.g., `./lidar_driver`).
- `port` (str, optional): The serial port for communication with the Lidar (default is `/dev/ttyUSB0`).
- `baud` (str, optional): The baud rate for communication (default is `460800`).

### 2. `_parse_line(self, line)`
This method takes a line of data from the Lidar output, uses a regular expression to extract the angle and distance, and returns them as a dictionary.

#### Parameters:
- `line` (str): A line of data from the Lidar output.

#### Returns:
- A dictionary with keys `"ang"` (angle) and `"dist"` (distance), or `None` if the line is malformed.

### 3. `_read_sensor_output(self)`
This method continuously reads the Lidar data in a background thread and processes each line using the `_parse_line` method. It stores the parsed angle and distance values in the `self.data` dictionary.

### 4. `get(self, angle)`
This method returns the distance corresponding to a specific angle from the Lidar data.

#### Parameters:
- `angle` (int): The angle for which the distance reading is required.

#### Returns:
- The distance at the specified angle or `None` if the angle is not found in the data.

### 5. `get_all(self)`
This method returns a copy of all current Lidar readings stored in `self.data`.

#### Returns:
- A dictionary of all the angle-distance pairs.

### 6. `stop(self)`
This method terminates the Lidar process and stops the background thread reading data.

---

# First Round Algorithm Code : The explanation is already above and you can contemplate it by seeing the flowchart too thats why not explaining here :))



# Wall Following Robot Using Lidar

This repository contains the code for a wall-following robot that uses Lidar sensor data to navigate and avoid obstacles. The robot is capable of following either the left or right wall based on the proximity detected by the Lidar sensor. It uses a servo for steering and motors for movement. The Lidar data is processed in real-time to make decisions for navigation and wall-following.

## Overview

The robot continuously reads data from a Lidar sensor to detect walls on the left and right. Based on the proximity of the walls, the robot adjusts its movement to follow the closer wall. It uses Lidar data to check for straight lines, intersections, and to ensure it follows the path correctly. If the robot detects an obstacle or a sharp turn, it adjusts its path accordingly.

## Features

- **Lidar-based Navigation**: The robot uses Lidar data to measure distances and detect walls on the left and right.
- **Wall Following**: The robot can follow either the left or right wall depending on which is closer.
- **Geometric Calculations**: The program uses linear regression to check if points form straight lines and calculates intersections for navigation.
- **Servo Steering**: The robot's steering is controlled using a servo, which adjusts based on Lidar readings.
- **Motor Control**: Motors are used for forward movement, with speed controlled by PWM (Pulse Width Modulation).

## How It Works :
## Initialization
## LidarReader: The LidarReader class interfaces with the Lidar sensor to continuously read distance data from various angles.
## Motor: The Motor class controls the movement of the robot.
## Servo: The Servo class controls the robot's steering mechanism based on the Lidar data.
## Wall Detection and Decision Making
## The robot continuously checks the distances to the left and right walls using the Lidar sensor. Based on which wall is closer, the robot decides which wall to follow:


## This is the stopping condition.


#  Round 2 Algorithm - Lap Completion with Obstacle Avoidance and Object Detection

Round 2 involves an enhanced version of our robot SMOKI, which autonomously completes three laps, avoiding obstacles and calculating the steering value based on object prioritization and boundary detection. Below is an in-depth look at the step-by-step algorithm implemented for this round.

##  Step-by-Step Algorithm Overview

###  Image Acquisition:
- The camera captures real-time images of the track and surroundings.

###  HSV Color Conversion:
- Convert the captured image from RGB to HSV (Hue, Saturation, Value) scale.
- Store all relevant line and object colors for further use.

###  Gaussian Blur:
- Apply Gaussian Blur to the frame to reduce noise.
- Based on predetermined HSV range, isolate the black border portion.

###  Black Border Detection:
- Use Canny Edge Detection to identify the black border walls.
- Apply Hough Line Probabilistic Transformation to determine acceptable border walls.

###  Border Masking:
- Create a border in the frame based on the detected lines.
- Mask out everything beyond the border to eliminate unnecessary information for the rest of the algorithm.

###  Line Detection (Blue or Orange):
- Identify lines using the predetermined HSV color range.
- Check for the blue or orange line in the frame.

### Slope Calculation:
- If a line is found, calculate the minimum and maximum slopes for both the blue and orange lines (if both are present).

###  Orientation Determination:
- If both blue and orange lines are detected, compare their slopes.
- Determine the clockwise or anti-clockwise orientation and store this in a variable for future reference.

###  Object Detection and Prioritization:
- Detect acceptable objects within the boundary wall.
- Assign a priority value to each object based on distance, orientation, and coordinates.
- Register only one object based on predetermined mathematical calculations.
- Calculate the steering value for navigation using a quadratic function based on the object's distance and position along the x-axis.

###  Serial Communication:
- Send the calculated steering value to the ESP32 via serial communication to adjust the robot's movement accordingly.

---

## Algorithm Explanation

The algorithm begins with image acquisition, where the camera captures real-time images of the track and the surrounding environment. These images are then processed by converting the RGB color space to the HSV (Hue, Saturation, Value) color space, which facilitates better color segmentation. This conversion is crucial for accurately detecting the track lines and objects, as it helps isolate relevant colors regardless of the lighting conditions in the environment.
To reduce noise in the captured frames, Gaussian blur is applied. This blurring operation smooths the image, making the subsequent steps, such as line and object detection, more reliable. After blurring, the algorithm isolates the black border of the track. The black border is then further processed using Canny Edge Detection, a technique that identifies edges in the image, and the Hough Line Transform to detect the boundaries that form the track walls. These steps allow the system to focus only on the track's relevant sections, effectively eliminating irrelevant background data.
Once the black border is identified and masked out, the algorithm proceeds to line detection. Using a predetermined HSV range, the system looks for blue and orange lines that represent the track’s guiding paths. These lines are critical for the robot’s navigation, and the system checks for their presence in the image to determine the robot's position relative to the track.
If either a blue or orange line is found, the algorithm calculates the slope of these lines. Specifically, the algorithm computes the minimum and maximum slopes for both the blue and orange lines (if both are present). These slope values are important for determining the orientation of the robot, as they provide information about whether the robot is traveling in a clockwise or anti-clockwise direction around the track. This step is essential for the robot to navigate turns and adjust its path as needed.
In parallel, the object detection mechanism is employed to identify obstacles within the track’s boundary walls. The detected objects are prioritized based on their distance, orientation, and coordinates within the frame. Using mathematical calculations, the algorithm determines the most relevant object and registers it for navigation. The robot then calculates a steering value using a quadratic function, which takes into account the object's distance and its position along the x-axis. This steering value is crucial for adjusting the robot's movement and ensuring it remains on track while avoiding obstacles.
Finally, the algorithm sends the calculated steering value to the ESP32 through serial communication, which adjusts the robot's movement accordingly. This real-time control ensures that the robot remains on its intended path, whether it's navigating straight sections of the track or making turns to avoid obstacles.
In terms of the underlying processes, the use of HSV conversion enhances the robot's ability to reliably detect track lines in varying lighting conditions, while Gaussian blur reduces noise that could otherwise interfere with detection. Hough Line Transform and Canny Edge Detection are pivotal in accurately identifying track boundaries, allowing for effective masking of the irrelevant parts of the frame. The slope comparison between the detected lines informs the robot's orientation, enabling it to discern whether it's moving clockwise or anti-clockwise on the track. The object prioritization system ensures that only the most relevant obstacles influence the robot’s decisions, optimizing its path-planning efficiency. The final step in the algorithm—the calculation and communication of the steering value—ensures that the robot can make precise, real-time adjustments to its movement.

## **Flowchart**

```mermaid

flowchart TD
    A[Start] --> B[Capture Image]
    B --> O{Object Detected?}

    %% Object Detected Branch
    O -->|Red Object| P[Steer Right with PID]
    O -->|Green Object| Q[Steer Left with PID]
    P --> N[Continue Navigation]
    Q --> N

    %% No Object Detected Branch → Round 1 Logic
    O -->|No| C{Line Detected?}
    
    %% Line Detected = Yes
    C -->|Yes| D{Orientation Set?}
    D -->|Yes| E[Line Count ++]
    D -->|No| F[Fix Orientation for Next Run and Line Count ++]
    E --> G{LineCount >= 12 AND LastLine > 1500ms AND FloorDist < 1500?}
    F --> G
    G -->|Yes| H[Initiate Parking Maneuver]
    G -->|No| K[Use Weighted Average from LIDAR to Find Best Path]

    %% Line Detected = No
    C -->|No| X{LineCount >= 12 AND LastLine > 1500ms AND FloorDist < 1500?}
    X -->|Yes| H
    X -->|No| I[LIDAR Scan Image]
    I --> K
    
    %% Common Path
    K --> M[PID Calculates Steering Value]
    M --> N[Continue Navigation]
```
<p align="center">

>[!IMPORTANT]
The second round has the same code files as first round just instead of the 1st round main code, it has the second round main code and instead of lidar first round, it has lidar second round 

# 2nd round algorithm code explanation:
  ## Lidar Code:
  
  

# LidarReader Class Explanation

This Python code defines a `LidarReader` class that is responsible for reading data from a LIDAR sensor, clustering the data points, and calculating the centroid of detected objects in the scan. Below is a breakdown of how it works:

## Key Components

### 1. **Imports**
- **`subprocess`**: To handle the LIDAR sensor process and capture its output.
- **`threading`**: Used to run a background thread to read sensor data in real-time.
- **`re`**: Regular expression to parse data.
- **`math`**: Provides mathematical functions like trigonometric and distance calculations.

### 2. **Global Clustering Parameters**
Global parameters that define constraints for the clustering process:
- `MIN_CLUSTER_POINTS`, `MAX_CLUSTER_POINTS`, etc., control how the code clusters LIDAR points (e.g., the minimum number of points required to form a valid cluster or the maximum allowed cluster width).

### 3. **LidarReader Class**

#### `__init__(self, path, port="/dev/ttyUSB0", baud="460800")`
This method initializes the `LidarReader` object. The `subprocess.Popen` starts the LIDAR sensor process and establishes communication with it using the provided serial port and baud rate. A background thread is also started to read sensor data.

#### `_parse_line(self, line)`
A helper function that reads each line of the sensor output. It uses a regular expression to extract the angle (`ang`) and distance (`dist`) for each data point. It returns these values as a dictionary: `{"ang": <angle>, "dist": <distance>}`.

#### `_read_sensor_output(self)`
Reads output from the LIDAR sensor line-by-line. It decodes the data, parses it with `_parse_line`, and stores the angle-distance pairs in `self.data`, which holds all the sensor measurements as `{angle: distance_mm}`.

#### `get(self, angle)`
Returns the distance (in mm) for a specific angle. If the angle is not found, it returns 0.

#### `get_all(self)`
Returns a full dictionary of all angle-distance pairs collected from the LIDAR sensor.

#### `stop(self)`
Terminates the LIDAR sensor process.

### 4. **Clustering Helpers**

#### `_cluster_max_width(self, cluster)`
Calculates the "width" of a cluster of points. This is the distance between the first and last point in the cluster.

#### `_cluster_centroid(self, cluster)`
Calculates the centroid (average x, y position) of a cluster of points and returns it in meters (since LIDAR points are in mm).

### 5. **`get_clusters(self)`**
This function processes the LIDAR data and identifies clusters:
- It reads all the LIDAR data and starts with an empty `current_cluster`.
- It iterates over the LIDAR scan data (from `scan_range_min` to `scan_range_max` angles) and converts the polar coordinates (angle and distance) to Cartesian coordinates (x, y).
- It then calculates the distance between consecutive points. If the distance exceeds the threshold (`POINT_DIST_THRESH`), the current cluster is saved, and a new cluster begins.
- After finishing the iteration, the function processes the clusters:
    - It checks if each cluster meets the required size and width criteria (`MIN_CLUSTER_WIDTH <= width <= MAX_CLUSTER_WIDTH`).
    - It calculates the centroid and width for each valid cluster and stores the results.

### 6. **Finding the Nearest Cluster**
After clustering, the function identifies the nearest cluster based on its centroid. The nearest cluster is determined by the minimum Euclidean distance from the origin (0, 0) to the centroid of the cluster. It returns the coordinates (centroid) of the nearest cluster, or `(None, None)` if no clusters are found.

## Summary of Process Flow:
1. The `LidarReader` continuously reads data from the LIDAR sensor.
2. The data is parsed and stored in a dictionary with angles as keys and distances as values.
3. The `get_clusters` method processes the data to group points into clusters based on distance between consecutive points.
4. For each cluster, it calculates the width and centroid.
5. Finally, it finds and returns the centroid of the nearest cluster, which represents the closest object detected by the LIDAR.

This code helps in processing LIDAR data to detect objects and determine their position relative to the sensor.

---
---

# 2ND ROUND MAIN CODE EXPLANATION(secondround.py) :

# Robot Navigation and Object Detection System

## Overview

This script is designed to control a robot equipped with multiple sensors, including a **LIDAR**, **Gyroscope**, **Camera**, and **Motor**. The robot can perform tasks like object detection, wall-following, and parking based on sensor data. The system utilizes object detection, steering adjustments, and proximity checks to navigate in its environment.

## Libraries and Modules

### Imported Libraries:

- **`cv2` (OpenCV)**: For processing camera frames and handling image manipulation tasks such as object detection and contour finding.
- **`time`**: Provides time-related functions to handle delays and timers in the robot's operations.
- **`math`**: Provides mathematical functions for geometric and trigonometric calculations.
- **`numpy`**: Used for numerical operations, particularly with arrays for image processing and object detection.
- **`pigpio`**: For controlling Raspberry Pi GPIO pins, which interact with the robot's hardware (e.g., motors, servos).
- **`scipy`**: Used for statistical operations like linear regression (for data processing).
- **`shapely.geometry`**: Used for geometric calculations, particularly with polygons and points for movement tracking.

### Custom Modules:

- **`utility`**: Contains helper functions like `clamp`, `map_range`, and `steer` for controlling values and the robot's steering.
- **`line_checks`**: Contains functions to check line geometries, like checking if lines are perpendicular, parallel, or calculating intersections.
- **`servo`, `lidar_reader`, `gyro_reader`, `motor`, `button`, and `camera_reader`**: Custom classes for controlling servos, reading LIDAR and gyroscope data, motor control, button input handling, and camera image capturing.

## Key Constants and Variables

### Object Constants:
- **`max_width`**: The maximum width of an object the robot will interact with.
- **`steering_limit`**: The maximum steering angle the robot can handle.
- **`obj_steer_err`**: Error margin for steering when interacting with objects.
- **`minimum_y_for_object`, `minimum_width_for_object`**: Minimum criteria for detecting objects in the environment.

### Global Variables:
- **`direction`**: Tracks the direction the robot is moving (left or right).
- **`speed`**: Controls the current speed of the robot.
- **`parking_flag`**: Indicates whether the robot is currently parking.

## Hardware Setup

### Initializing Hardware:
- **`pigpio.pi()`**: Initializes the GPIO library to control hardware pins on the Raspberry Pi.
- **`LIDAR`**: Reads distance data from the LIDAR sensor, which helps the robot detect walls and obstacles.
- **`Gyroscope`**: Provides yaw (orientation) data to help the robot adjust its position and navigate.
- **`Servo`**: Controls the steering of the robot.
- **`CameraReader`**: Captures frames from the robot's camera for object detection.
- **`Motor`**: Controls the robot's speed and direction based on sensor inputs.
- **`Button`**: Detects button presses for starting or stopping the robot’s operations.

### GPIO Setup:
- **LED_PIN**: Controls an LED to indicate the status of the robot.

## Main Logic

### Button Handling:
The robot listens for button presses to control the robot's start/stop operations and parking functions. Each press toggles the parking mode and starts the parking process based on the robot's surroundings.

if state == 1 and prev_btn_state == 0:  # If button is pressed
    ...
    if (btn_cnt % 2) == 1 and parking_start_flag is True:
        ...

---
# Parking Logic:
The robot performs parking actions based on its position relative to walls. It uses the LIDAR and Gyroscope to adjust its yaw (orientation) and steer itself into a parking spot.


---
# Object Detection:
## The robot uses camera frames to detect objects in its environment. The object detection system is based on HSV color ranges. The system marks objects of interest with bounding boxes and adjusts the steering based on their position.


---
# Wall-Following:
## The robot can follow walls either on the left or right based on sensor data. The LIDAR readings are used to guide the robot's steering, ensuring it stays at an appropriate distance from the wall.


---
# Lidar and Gyroscope integration :
## The robot combines LIDAR and Gyroscope data to adjust its movement and maintain a correct path. The LIDAR helps in detecting obstacles, while the Gyroscope helps in correcting the robot's orientation.


---

# Collision Detection:
## The robot uses a combination of LIDAR and object detection to avoid collisions. When an object is detected too close, the robot stops and waits until the area is clear.


---

# Final Parking:
## The robot follows the parking logic to maneuver into a designated parking spot. It uses LIDAR readings to ensure proper alignment and uses the gyroscope to adjust its final position.


---
# Main loop :
## The robot continuously checks for sensor data, adjusts its speed, direction, and steering, and displays the current camera frame with object detection results. It stops when the button is pressed again, or a specific condition is met.


---
#
  # THATS ALL FROM US
</p>



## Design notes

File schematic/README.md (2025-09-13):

# SCHEMATIC :



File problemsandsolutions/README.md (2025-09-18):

# Problems Faced and Solutions Implemented :
1. #  CAMERA ISSUE :
One of the first challenges we encountered was with the SJCAM C200 action camera. Our goal was to use it as the primary vision system for the robot, automatically starting up in action camera mode at power-on so that it could immediately begin capturing video. However, the camera’s firmware design posed a significant obstacle: in order to activate recording mode, the user is required to press two buttons in sequence. Since our robot’s physical interface only allows automation of a single power or trigger button, this created a serious limitation. In a robotics application where everything should initialize seamlessly on startup, having to manually press multiple buttons was simply not acceptable. After repeated trials and attempts to work around this behavior, it became clear that the SJCAM C200 could not meet our requirements in its default form.
The solution was drastic but effective: we removed the action camera role entirely and repurposed the device to function strictly as a PC camera on startup. By rewiring the system and bypassing the dual-button activation sequence, we ensured that the camera would automatically initialize in webcam mode as soon as power was applied. This change eliminated the need for manual intervention and brought the system into alignment with the principle of full automation. Although it meant giving up native onboard recording features, the trade-off was worthwhile because it provided reliable, hands-free video capture directly integrated with the rest of the robot’s processing pipeline. This decision not only streamlined startup but also reduced potential points of failure in field deployment.

# CAMERA BEFORE AND AFTER :

| **Before (SJCAM C200 Action Camera Mode)** | **After (Rewired for Auto PC Camera Mode)** |
|---|---|
| | |

2. # FAULTY AND UNRELIABLE SONAR SENSORS : A second major issue arose from our initial reliance on ultrasonic sonar sensors for distance measurement and obstacle detection. Sonar modules are attractive because they are inexpensive, lightweight, and widely available. However, during testing we discovered several critical shortcomings. Low-cost sonar sensors proved to be highly unreliable, with inconsistent readings that were easily disrupted by soft materials, angled surfaces, or environmental noise. Furthermore, using multiple sonar units in parallel introduced cross-interference, leading to false echoes and data corruption. The wiring complexity increased with each additional module, and integrating them into the PCB led to higher chances of error, noise coupling, and troubleshooting overhead. For a robot that demands precision, these limitations quickly became unacceptable.
To address this, we transitioned from sonar sensors to a LiDAR-based solution. Unlike sonar, LiDAR provides much greater coverage with a single sensor, reducing both hardware complexity and software overhead. With LiDAR, the robot was able to generate accurate distance measurements over a wide field of view, allowing it to map its environment with higher confidence and fewer blind spots. This not only simplified the PCB layout by removing multiple unreliable sonar channels but also improved system reliability by eliminating the issues of echo interference and inconsistent readings. The result was a cleaner, more efficient sensing system that required less debugging while dramatically improving environmental awareness and navigation capabilities.
Together, these problem-solving decisions reflect the iterative engineering process behind the robot. Each limitation encountered — from the camera’s startup logic to the sonar sensor unreliability — forced us to rethink the design and implement more robust alternatives. By replacing manual-dependent hardware with automated solutions and swapping error-prone sensors for advanced LiDAR technology, we made the robot more reliable, maintainable, and capable of performing in real-world conditions.


---
---

Another major advantage is range and density of data. Cheap sonar sensors typically measure reliably only within 2–4 meters, and often with wide, imprecise beams that blur object edges. The RPLIDAR C1, on the other hand, provides coverage up to 12 meters with thousands of distance points per second, creating a detailed map of the robot’s environment. This higher density of data not only improves navigation but also enables advanced behaviors such as path planning, obstacle avoidance, and dynamic re-routing in real time. For robotics projects that require autonomy and reliability, these differences are critical.
Finally, the use of RPLIDAR reduces design complexity. Instead of wiring and calibrating multiple sonar units, the robot only needs a single LiDAR sensor connected via USB or UART. This simplifies the PCB layout, minimizes error sources, and improves overall system reliability. While the upfront cost of RPLIDAR C1 is higher than a set of cheap sonars, the trade-off in performance, reliability, and maintainability makes it a far better choice for serious robotics applications.
In summary, while sonar sensors are useful for very simple distance measurements, they quickly become a bottleneck in robotics projects due to unreliability and complexity. The RPLIDAR C1 provides accurate, wide-range, 360° scanning with minimal wiring and maximum reliability, making it vastly superior for autonomous navigation and mapping in our robot.

---

3. # Raspberry pi 5 startup issue:
   One of the most frustrating challenges we faced during development was with the Raspberry Pi 5. Our intention was to use the Pi 5 as the main controller for the robot since it offers more processing power, faster I/O, and overall better hardware capabilities compared to the Pi 4. However, despite its advantages, we ran into a critical issue: we could not get our startup automation to work properly on the Pi 5.
We initially configured crontab (@reboot) entries to run our control scripts automatically as soon as the Pi booted. This is a standard and reliable method that works flawlessly on earlier Raspberry Pi models, including the Pi 3 and Pi 4. Unfortunately, on the Pi 5, the scripts would not execute at startup no matter how many times we adjusted the configuration. We tested different approaches:
Using crontab -e with the @reboot directive.
Adding startup commands to rc.local.
Creating and enabling systemd service files to ensure the scripts launched during the boot sequence.
Testing both root-level and user-level crontab entries.
Delaying script execution with sleep commands in case the services were loading too early.
Despite all these attempts, the Pi 5 consistently refused to launch the scripts on startup. The behavior was puzzling because manual execution of the same scripts after boot worked perfectly, proving that the problem was tied specifically to the initialization process. To rule out OS-related issues, we tried multiple operating system images, including Raspberry Pi OS Lite, Raspberry Pi OS with desktop, and even different kernel updates. Each attempt produced the same result: startup automation simply failed on the Pi 5.
After spending significant time troubleshooting, we made the decision to switch back to the Raspberry Pi 4B, which has a well-tested ecosystem. On the Pi 4, crontab worked immediately without any issues, and our scripts ran at startup exactly as expected. This confirmed that the problem was not with our code or configuration, but likely with the Raspberry Pi 5’s still-evolving software support or OS compatibility at the time of testing. While the Pi 5 hardware is superior, the lack of reliable startup automation meant it was not viable for this project, where seamless initialization is critical for autonomous operation.
In the end, moving to the Pi 4B provided stability and reliability, even if it meant sacrificing some of the performance gains of the Pi 5. For robotics, dependability during startup proved to be far more important than raw computing power, and until Raspberry Pi OS matures further for the Pi 5, the Pi 4 remains the safer and more practical choice.


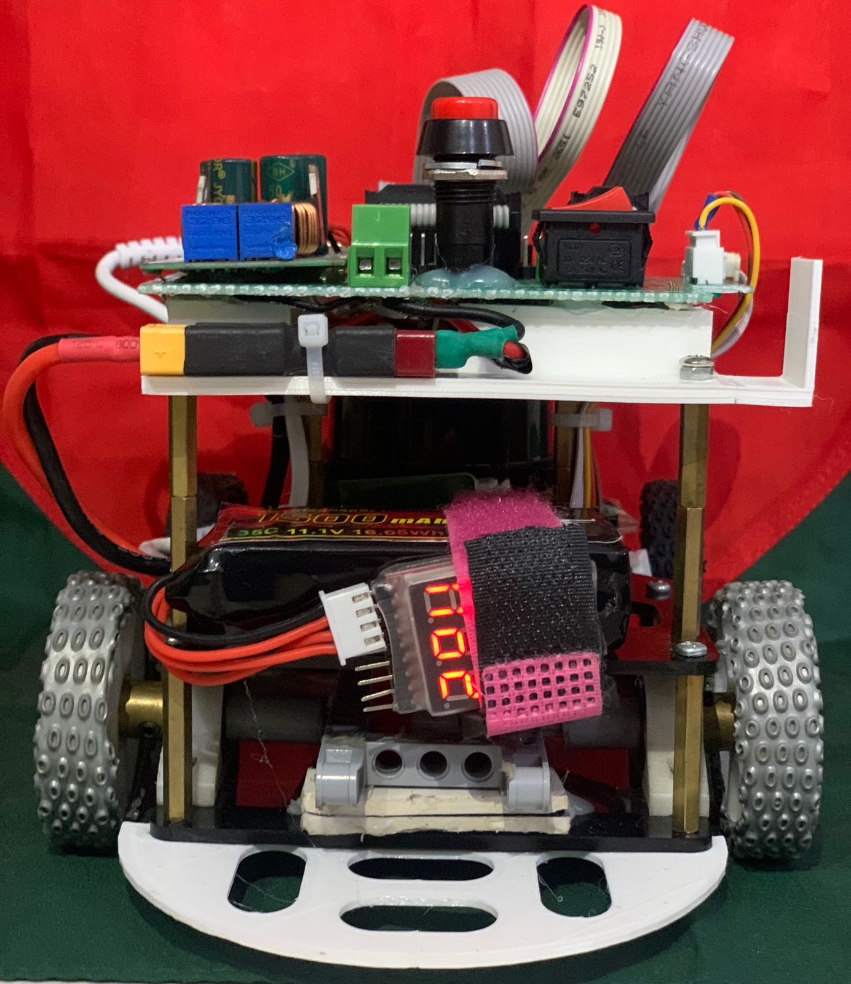
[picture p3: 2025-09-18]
v-photos/backphoto.jpeg

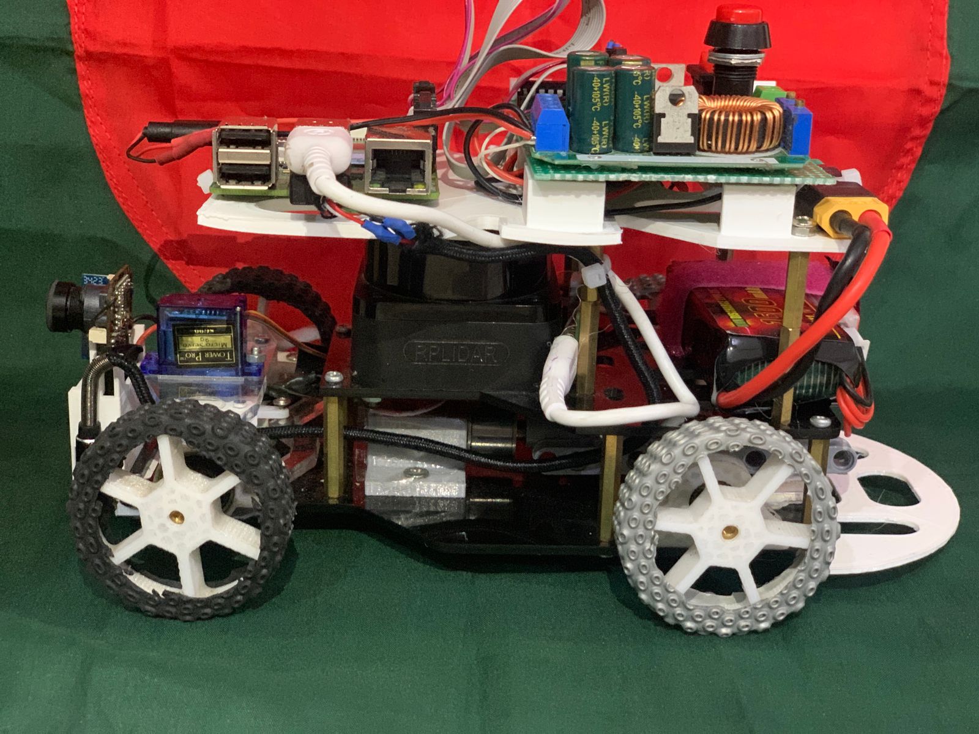
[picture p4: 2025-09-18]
v-photos/leftimage.jpeg

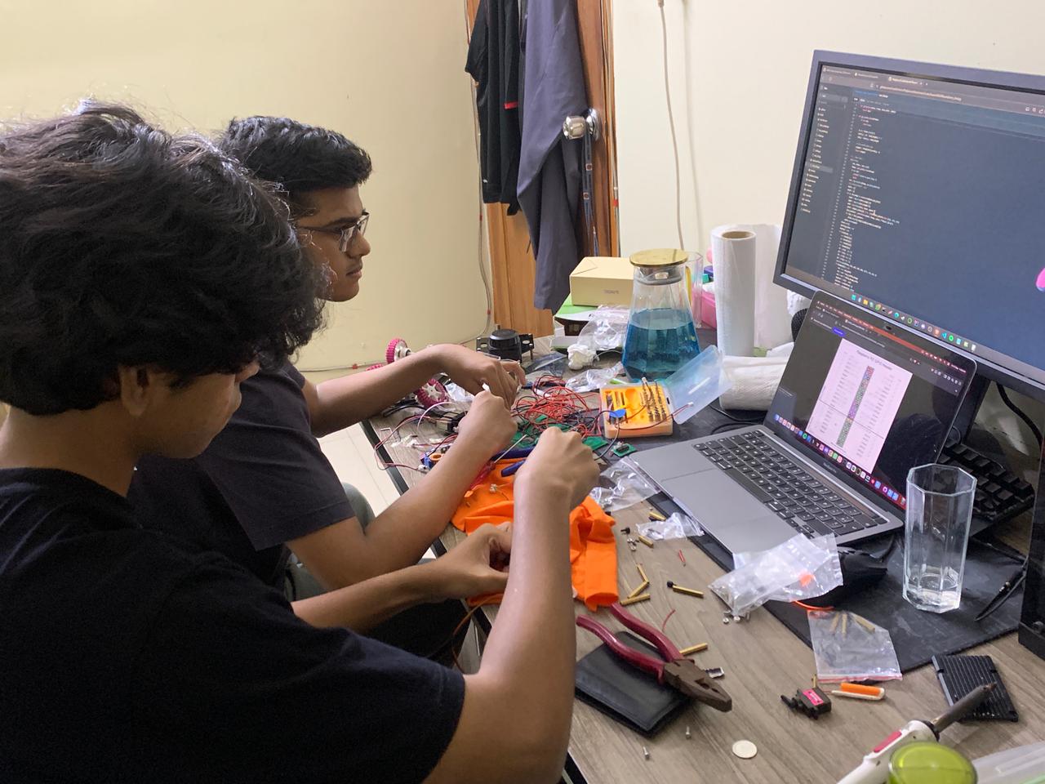
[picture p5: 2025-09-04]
t-photos/seriousteamphoto.jpg

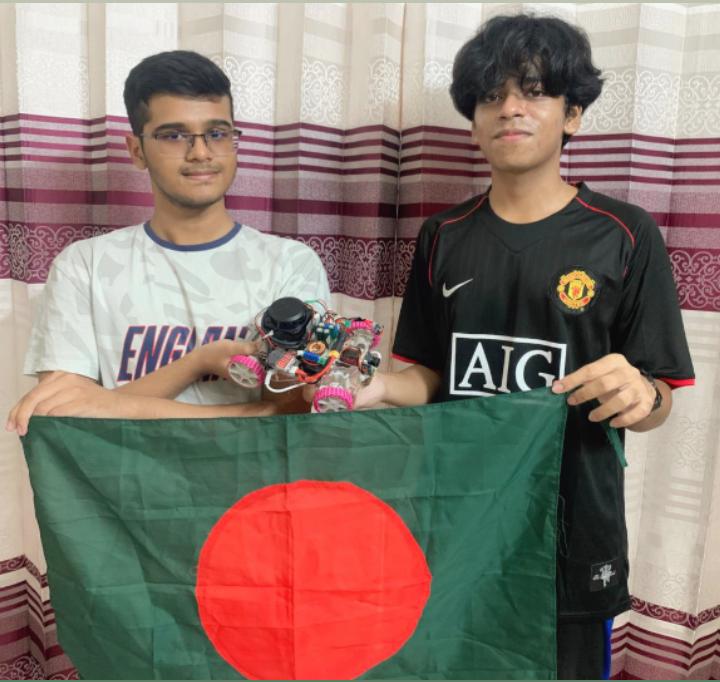
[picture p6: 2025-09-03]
t-photos/teamphoto.jpg

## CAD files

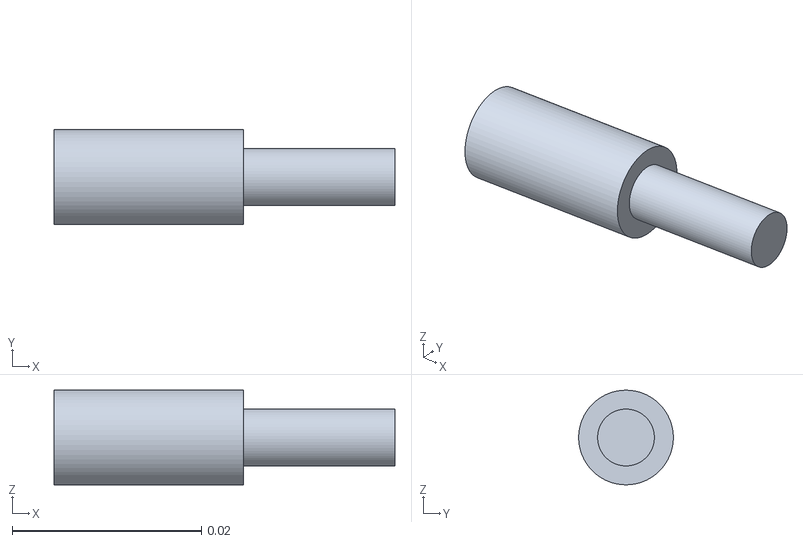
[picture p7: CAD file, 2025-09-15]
model/wheel coupler.stl
0.036 x 0.00999 x 0.01

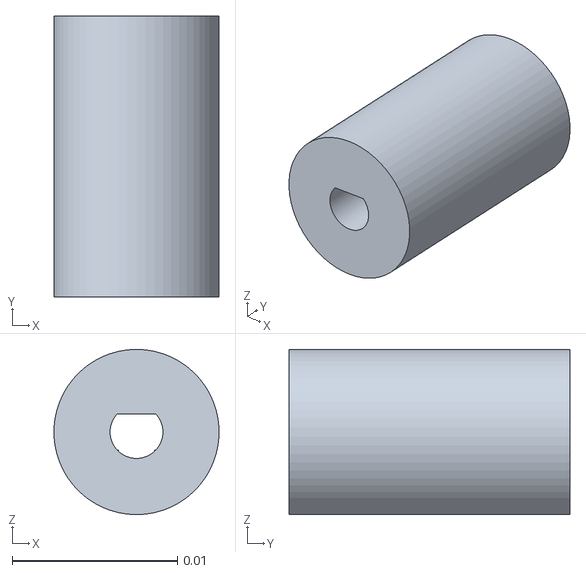
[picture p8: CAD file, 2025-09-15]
model/motor coupler.stl
0.00999 x 0.017 x 0.01

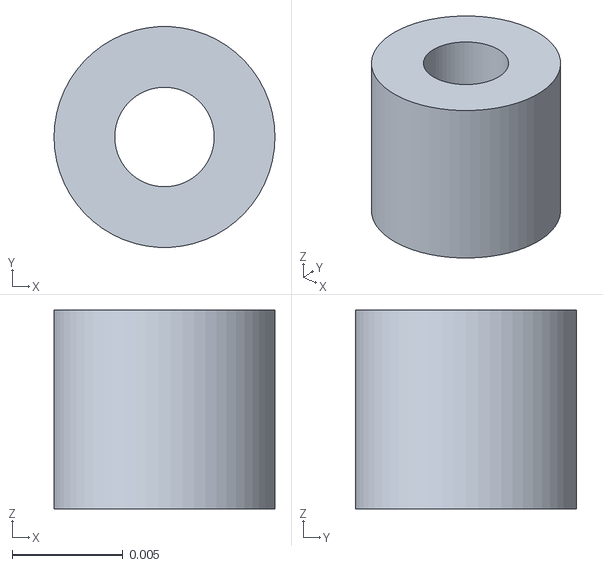
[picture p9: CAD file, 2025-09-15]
model/differential support.stl
0.01 x 0.00999 x 0.009

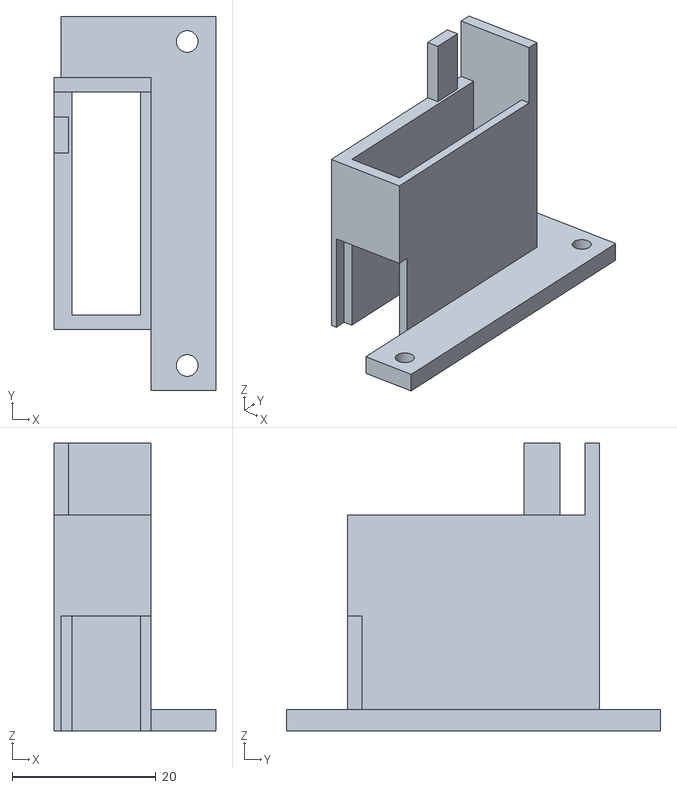
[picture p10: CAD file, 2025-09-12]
model/camera_holder.stl
22.5 x 52.0 x 40.0

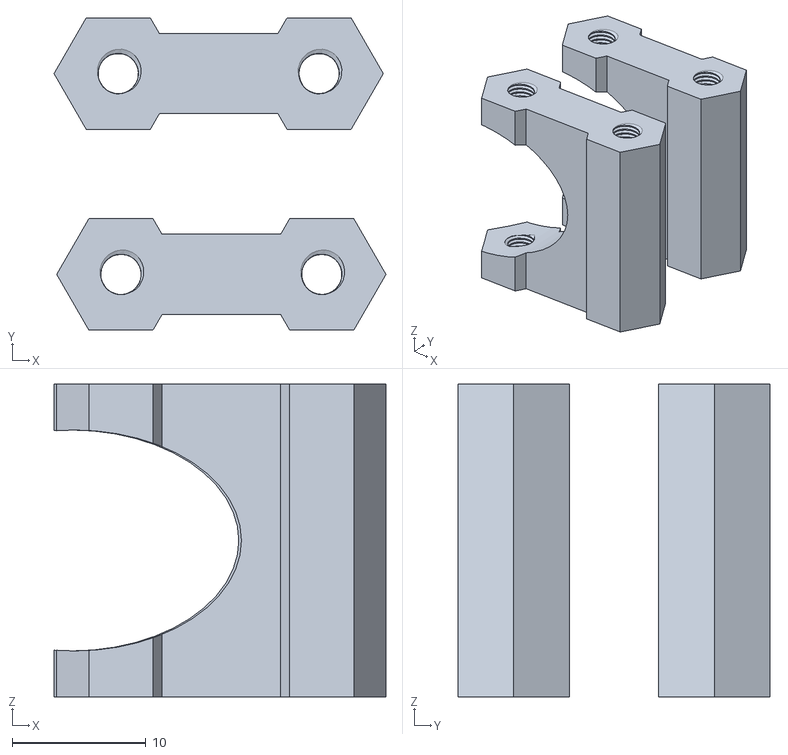
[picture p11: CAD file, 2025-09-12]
model/motor_driver_holder.stl
24.8 x 23.3 x 23.3

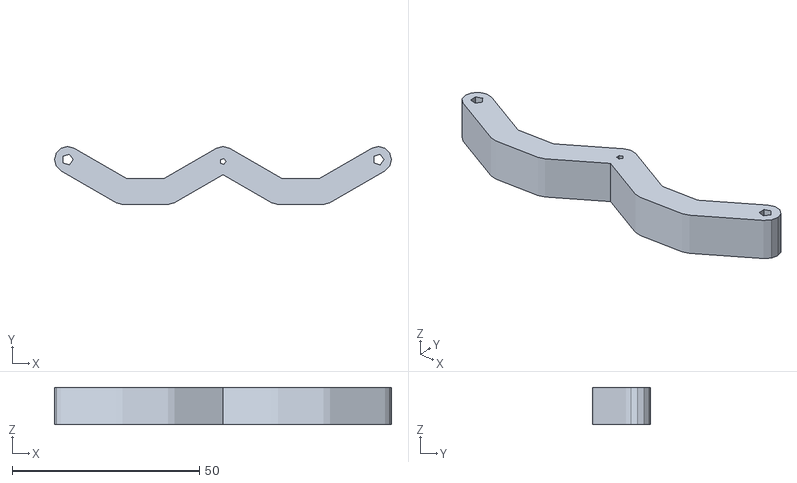
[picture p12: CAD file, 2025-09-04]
model/steering shaft.stl
90.0 x 15.5 x 10.0

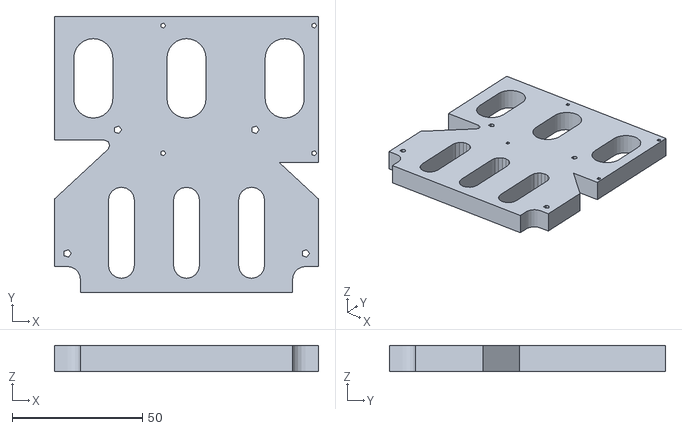
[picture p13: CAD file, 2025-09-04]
model/top floor.stl
101.5 x 106.0 x 10.0

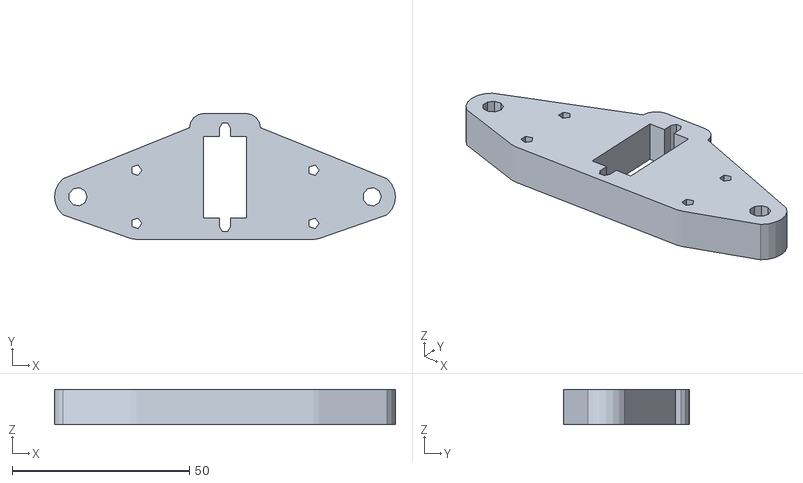
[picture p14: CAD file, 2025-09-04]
model/chassis-steering.stl
96.2 x 35.5 x 10.0

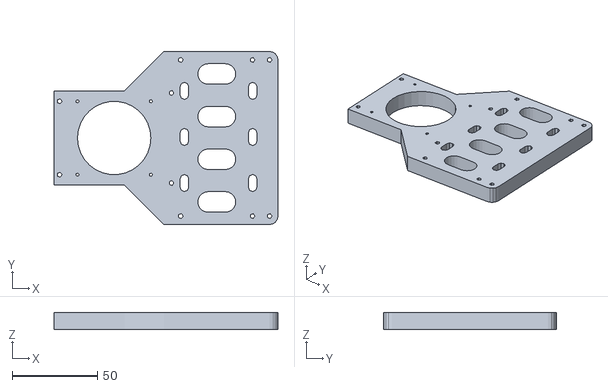
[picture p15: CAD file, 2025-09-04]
model/2nd floor.stl
131.3 x 101.5 x 10.0

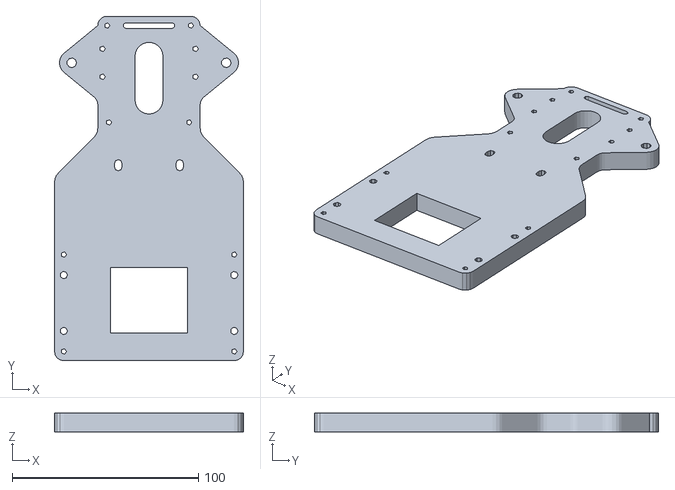
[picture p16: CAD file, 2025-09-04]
model/chassis - 1st floor.stl
101.5 x 185.0 x 10.0

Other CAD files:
model/2nd floor.dxf
model/chassis - 1st floor.dxf
model/chassis-steering.dxf
model/steering shaft.dxf
model/top floor.dxf

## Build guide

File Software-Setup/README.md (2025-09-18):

# 🛠️ Software & Tools Used  

Our project required a wide range of software for **3D design, circuit simulation, PCB layout, coding, and system setup**. Each tool was chosen for its specific strengths, ensuring that every part of the robot — from the mechanical design to the embedded software — was well-supported. Below is a detailed overview of the software stack we used:  

---

### ⚙️ Onshape (Mechanical CAD Design)  
Onshape was used to design the **mechanical parts and assemblies** of the robot. Being a cloud-based CAD tool, it allowed for real-time collaboration and easy access from multiple devices. We modeled the robot chassis, servo holders, camera mounts, and other 3D-printable parts directly in Onshape, ensuring precision and proper fit before manufacturing. The parametric modeling features helped us quickly adjust dimensions when we iterated through multiple versions of the chassis.  

---

### ⚙️ Tinkercad (Circuit Prototyping & Simulation)  
Before moving into PCB manufacturing, we used Tinkercad’s easy-to-use **circuit simulator** to prototype the wiring of sensors, motors, and LEDs. This was especially useful during the early stages of development to quickly validate logic, check pinouts, and test simple behaviors without needing to solder or breadboard everything. While limited compared to professional EDA software, Tinkercad gave us a fast way to visualize and debug small subsystems before moving to a full schematic.  

---

### ⚙️ KiCad (PCB Design & Schematic Capture)  
KiCad was the main software used to design our **custom PCB**. We created full schematics for power management, motor drivers, and signal routing, then laid out the PCB with proper traces, vias, and ground planes. KiCad’s ERC (Electrical Rule Check) and DRC (Design Rule Check) ensured that our design was valid before manufacturing. The ability to generate **Gerber files** directly from KiCad made it easy to send our board for fabrication. Over time, we revised multiple PCB versions in KiCad, improving power regulation and simplifying wiring complexity with each iteration.  

---

### ⚙️ Raspberry Pi OS & Setup Tools  
For the main controller, we used **Raspberry Pi OS** on both Raspberry Pi 4B and Raspberry Pi 5. The OS was set up with Python libraries such as OpenCV, RPi.GPIO, smbus2 (for I²C communication with sensors like the MPU-6050), and pyserial for UART. We configured **crontab** and **systemd services** for startup automation, although we faced issues with Pi 5 where startup scripts wouldn’t execute properly. We also installed development tools such as `git`, `pip`, and `ssh` for remote management. The OS environment provided a stable platform to integrate sensing, motor control, and computer vision tasks.  

---
---

### ⚙️ Python (Core Robotics Control)  
Python served as the **primary programming language** for the project. We used it for motor control logic, servo positioning, sensor data processing, and integrating LiDAR input with navigation algorithms. Libraries like **OpenCV** were critical for handling camera input, while **matplotlib** was used during experiments to visualize sensor data. Python scripts were also linked with the PCB’s power logic and motor drivers to allow for full software-based control.  

---

### ⚙️ OpenCV (Computer Vision)  
OpenCV was employed for image capture and processing from the SJCAM (in PC camera mode) and later integrated into navigation routines. It enabled real-time frame acquisition, preprocessing (grayscale conversion, edge detection), and served as the foundation for potential object detection tasks. Even though the final implementation leaned more on LiDAR for reliable mapping, OpenCV gave us the framework to expand into visual-based navigation if needed.  

---

### ⚙️ GitHub (Version Control & Collaboration)  
All project files — from code and schematics to models and reports — were maintained in a **GitHub repository**. This ensured that every iteration was tracked through commits, and multiple collaborators could work on the same project without conflicts. GitHub Actions also gave us CI/CD capability, and the README served as the central documentation hub for all hardware and software.  

---

### ⚙️ Additional Tools & Utilities  
- **VS Code**: Main IDE for Python and embedded development, with extensions for Git integration.  
- **Inkscape / Figma**: For creating diagrams, flowcharts, and refining visuals for the README.  
- **CoolTerm / Serial Monitor**: For debugging UART communication with microcontrollers.  
- **Jupyter Notebooks**: Used during experiments to log and visualize data from sensors.  

---

## 🧩 Summary  
This stack of tools allowed us to cover every aspect of the robot: **Onshape and Tinkercad for physical and virtual prototyping, KiCad for electronics design, Raspberry Pi OS and Arduino IDE for firmware, Python and OpenCV for intelligence, and GitHub for collaboration**. Each tool played a specific role in ensuring that our design was not only functional but also well-documented and reproducible.

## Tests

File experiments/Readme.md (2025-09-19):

# 🤖 *Our Previous SMOKI**(MODEL -1 )

**SMOKI**, developed by **MAYERDOA ROBOTICS**, represents one of our earlier robotic innovations. This guide provides step-by-step instructions, visual aids, and tips for assembling the bot.

---

## 🛠️ 3D Printed Baseplate

baseplate3

The 3D-printed baseplate provides a durable and modular foundation for SMOKI, enabling precise component placement and efficient wiring.

---

## 🛠️ Installation Spacers (M3 35.5 mm spacers)

spacers1
spaces

Spacers ensure proper alignment and balance, simplifying assembly and optimizing SMOKI’s performance.

---

## ⚙️ Motor Installation



Motors are critical for SMOKI’s movement, offering durability and precise control. Secure installation minimizes vibrations and ensures smooth operation.

---

## 🔧 Rear Axle Gear Assembly

RAA1

The rear axle assembly delivers torque and drive, ensuring stability and efficient power transfer for smooth mobility.

---

## 🛠️ Ackermann Steering System Assembly

AxleCoupler1

This system provides SMOKI with precise steering and dynamic navigation capabilities.

---

## 🖥️ Main PCB Overview

PCB

The PCB integrates all electronic components, ensuring efficient power management and clear communication for reliable operation.

---

# FINAL LOOK

finallook

---

**SMOKI** stands as a milestone in our robotics journey. For our latest innovations, stay connected with **MAYERDOA ROBOTICS**!

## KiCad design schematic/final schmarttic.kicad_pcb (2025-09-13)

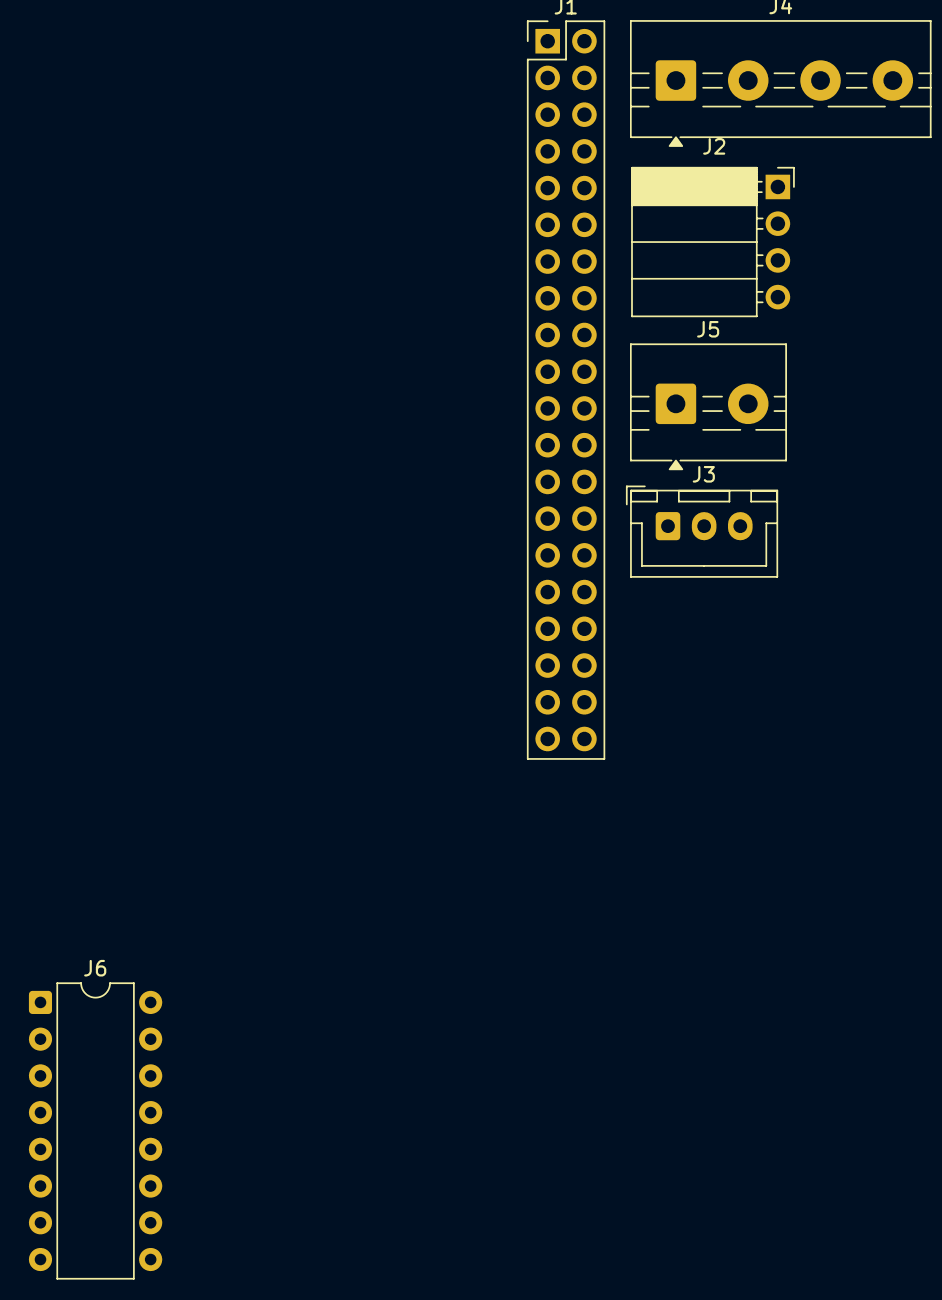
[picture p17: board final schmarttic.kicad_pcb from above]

Board: 2 copper layers, 6 parts (0 on the bottom side), 8 nets, no tracks yet.

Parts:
J1: rasberry pi; PinHeader_2x20_P2.54mm_Vertical
J2: i2c port for mpu 9250; PinSocket_1x04_P2.54mm_Horizontal
J3: servo motor; JST_XH_B3B-XH-A_1x03_P2.50mm_Vertical
J4: Screw_Terminal_01x04; TerminalBlock_MaiXu_MX126-5.0-04P_1x04_P5.00mm
J5: Screw_Terminal_01x02; TerminalBlock_MaiXu_MX126-5.0-02P_1x02_P5.00mm
J6: Conn_02x08_Counter_Clockwise; DIP-16_W7.62mm

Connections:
unnamed: J1.1, J2.4
unnamed: J1.2, J3.1
unnamed: J1.3, J2.1
unnamed: J1.5, J2.2
unnamed: J1.6, J3.2
unnamed: J1.7, J3.3
unnamed: J1.9, J2.3
unnamed: J4.3, J5.2

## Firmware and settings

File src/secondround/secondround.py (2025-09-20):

import cv2 as cv  # Import OpenCV for image processing
import time  # Import time for delays and timing operations
import math  # Import math for mathematical operations
from utility import clamp, map_range, steer  # Import utility functions for clamping values, mapping ranges, and controlling the steering
from line_checks import coords, linearity, are_perpendicular, get_intersection, are_parallel, get_front_line, angle, get_yaw_diff, inside_polygon  # Import line check functions
from servo import Servo  # Import the Servo class for controlling servos
from lidar_reader import LidarReader  # Import LidarReader for handling LIDAR sensor data
from gyro_reader import GyroReader  # Import GyroReader for handling gyroscope data
from motor import Motor  # Import Motor class for controlling motors
import numpy as np  # Import numpy for numerical operations, particularly with arrays
from scipy.stats import linregress, false_discovery_control  # Import statistical functions
from line_plotter import line_show, point_show  # Import line plotting functions
from shapely.geometry import Point, Polygon  # Import Shapely for geometric operations
import pigpio  # Import pigpio for controlling Raspberry Pi GPIO pins
from button import Button  # Import Button class for handling button inputs
from camera_reader import CameraReader  # Import CameraReader class for reading camera frames

default_speed = 165  # Default speed setting for the robot

# Object constants
max_width = 80  # Maximum acceptable width for objects
max_x_delta_change = 177  # Maximum change in x-coordinate for objects
delta_change_ratio = 0.9  # Ratio for delta change in object positions
steering_value = 0  # Initial steering value
steering_limit = 75  # Maximum limit for steering value
obj_steer_err = 20  # Error margin for steering with respect to objects
width_for_constant_distance = 9  # Minimum acceptable width for constant distance detection
minimum_y_for_object = 10  # Minimum y-coordinate for valid object detection
band_height = 300  # Height of the band for object detection
minimum_width_for_object = 28  # Minimum width for valid object detection
obj_steer_boundary = 150  # Boundary for steering based on object distance
obj_steer_limit = 120  # Maximum limit for steering based on objects

# Initialize state variables
last_obj = 0  # Last object detected
last_obj_timer = 1.25  # Timer for last object detection
last_obj_found = -100  # Time when last object was found

direction = 0  # Direction flag (e.g., left or right)
col_flag = 0  # Collision flag (detecting collision)
col_timer = 3.2  # Collision detection timeout
col_yaw_timer = 1  # Yaw change detection timeout
col_yaw_risk_timer = 3.56  # Risk detection timeout for yaw
col_last_timer = -100  # Last time a collision was detected
parking_timer = -100  # Parking timer
col_yaw_update_tolerance = 12  # Tolerance for yaw update during collision
is_col = 0  # Boolean flag for collision state
corner = 0  # Number of corners the robot has completed
lap_cnt = 1  # Number of laps completed
last_err = 0  # Last steering error
speed = 0  # Current speed of the robot

parking_end_flag = False  # Flag for parking end
parking_start_flag = True  # Flag for parking start
too_close = False  # Flag for detecting if an object is too close

too_close_timer = 0  # Timer for too-close state
side_risk_dist = 185  # Side risk distance for avoiding obstacles

# Global variables for object detection boundaries
erre = 40
minimum_x_for_object = 100
maximum_x_for_object = 600
minimum_y_for_object = 230
maximum_y_for_object = 290
minimum_x_for_line = 200
maximum_x_for_line = 440
minimum_y_for_line = 330
maximum_y_for_line = 255

# Exclusion sets for object detection based on color
exclusion_sets = {
    0: (),  # No exclusions for color 0 (blue)
    1: (4,),  # Exclude color 4 (pink) for color 1 (orange)
    2: (),  # No exclusions for color 2 (green)
    3: (0, 1, 2, 4),  # Exclude colors 0 (blue), 1 (orange), 2 (green), and 4 (pink) for color 3 (red)
    4: (),  # No exclusions for color 4 (pink)
}

# First round setup for hardware components
pi = pigpio.pi()  # Initialize the pigpio library for GPIO control
lidar = LidarReader(path="/home/wro/rplidar_sdk/output/Linux/Release/ultra_simple")  # Initialize LIDAR sensor
gyro = GyroReader(freq=60.0)  # Initialize Gyroscope reader with frequency of 60 Hz
servo = Servo(4)  # Initialize the Servo object for controlling the servo on pin 4
cam_reader = CameraReader(pi, cam_pins=(20, 21), width=640, height=480)  # Initialize CameraReader for reading from camera
motor = Motor(pi)  # Initialize Motor object for controlling the robot's motors
btn = Button(pi, 16)  # Initialize Button object for handling button input on GPIO pin 16

LED_PIN = 9  # Define the pin number for the LED

# Set up the LED pin for output and initialize it to off
pi.set_mode(LED_PIN, pigpio.OUTPUT)
pi.write(LED_PIN, 0)

# Read initial LIDAR values for right and left walls
rwall = None
lwall = None
while rwall is None or lwall is None or lwall == 0 or rwall == 0:
    rwall = lidar.get(150)  # Get LIDAR reading at 150 degrees (right wall)
    lwall = lidar.get(30)   # Get LIDAR reading at 30 degrees (left wall)

print(f"rwall={rwall} lwall={lwall}")

# Function to load HSV color ranges from a file
def load_hsv_ranges(filename):
    hsv_ranges = []  # List to store HSV ranges
    with open(filename, 'r') as f:  # Open the file for reading
        for line in f:  # Read each line in the file
            line = line.strip()  # Remove leading/trailing whitespace
            if not line or line.startswith('#'):  # Skip empty or comment lines
                continue
            parts = line.split(',')  # Split the line by commas
            if len(parts) != 6:  # Check if the line has exactly 6 parts
                print(f"?? Skipping invalid line: {line}")
                continue
            hsv_range = list(map(int, parts))  # Convert the parts to integers
            hsv_ranges.append(hsv_range)  # Add the HSV range to the list
    return hsv_ranges  # Return the list of HSV ranges

# Load all HSV ranges from the file
all_hsv_ranges = load_hsv_ranges('hsv_values.txt')

# Select only lines 3 and 4 (index 2 and 3) from the HSV ranges
if len(all_hsv_ranges) < 4:
    print("? hsv_ranges.txt file must have at least 4 lines with valid HSV ranges.")
    exit()

# Define object and line HSV ranges based on the loaded values
object_hsv_list = [all_hsv_ranges[2], all_hsv_ranges[3]]
line_hsv_list = [all_hsv_ranges[0], all_hsv_ranges[1]]

# Define object colors in BGR format (for OpenCV)
object_colors = [
    (255, 0, 0),     # Blue
    (0, 165, 255),   # Orange
    (0, 255, 0),     # Green
    (0, 0, 255),     # Red
    (255, 0, 255)    # Pink (magenta)
]

# Resize masks helper function (to adjust mask size for frame dimensions)
def resize_mask(mask, width, height):
    return cv.resize(mask, (width, height), interpolation=cv.INTER_NEAREST)

# Function to get contours from a frame based on selected HSV range
def getContours(frame, current_index, draw_color):
    global all_hsv_ranges, exclusion_sets

    hsv = cv.cvtColor(frame, cv.COLOR_BGR2HSV)  # Convert frame to HSV color space

    # Start with full mask (everything allowed initially)
    mask = np.ones(hsv.shape[:2], dtype=np.uint8) * 255

    # Apply exclusions first (exclude certain colors based on the exclusion sets)
    if current_index in exclusion_sets:
        for idx in exclusion_sets[current_index]:
            lower_ex = np.array(all_hsv_ranges[idx][:3])
            upper_ex = np.array(all_hsv_ranges[idx][3:])
            exclusion_mask = cv.inRange(hsv, lower_ex, upper_ex)
            mask[exclusion_mask > 0] = 0  # Black out excluded pixels

    # Apply the selected HSV range for the current object
    lower = np.array(all_hsv_ranges[current_index][:3])
    upper = np.array(all_hsv_ranges[current_index][3:])
    selected_mask = cv.inRange(hsv, lower, upper)

    # Keep only pixels that are in both the allowed area and the selected range
    mask = cv.bitwise_and(selected_mask, mask)
    if current_index == 0:  # If the index is for the blue object, show the mask
        cv.imshow("blue", mask)
    if current_index == 1:  # If the index is for the orange object, show the mask
        cv.imshow("orange", mask)

    # Find contours in the mask
    contours, _ = cv.findContours(mask, cv.RETR_EXTERNAL, cv.CHAIN_APPROX_NONE)
    list = []

    for cnt in contours:  # Iterate through each contour found
        area = cv.contourArea(cnt)  # Calculate the area of the contour
        if area > 100:  # Only process contours with area greater than 100
            peri = cv.arcLength(cnt, True)  # Calculate the perimeter of the contour
            approx = cv.approxPolyDP(cnt, 0.02 * peri, True)  # Approximate the contour to a polygon
            x, y, w, h = cv.boundingRect(approx)  # Get the bounding rectangle for the contour
            x = int(x + w / 2)  # Calculate the center x-coordinate
            y = int(y + h / 2)  # Calculate the center y-coordinate

            rect = [x, y, w, h]  # Create a list with bounding box information
            if y > minimum_y_for_object:  # Only include objects below the minimum y threshold
                cv.circle(frame, (x, y), 6, draw_color, -1)  # Draw a circle at the center of the object
                list.append(rect)  # Add the object to the list

    return list  # Return the list of detected objects

# Function to get the middle portion of the frame based on y-coordinates
def get_middle_frame(frame):
    mask_pts = np.array([[0, minimum_y_for_object], [640, minimum_y_for_object], [640, maximum_y_for_object + erre], [0, maximum_y_for_object + erre]], np.int32)
    mask = np.zeros((480, 640), dtype=np.uint8)  # Create a mask for the specified region
    cv.fillPoly(mask, [mask_pts], 255)  # Fill the polygon defined by mask_pts with white
    frame = cv.bitwise_and(frame, frame, mask=mask)  # Apply the mask to the frame
    return frame  # Return the cropped frame

yaw = gyro.get_yaw()  # Get the initial yaw (orientation) from the gyroscope
true_yaw = yaw  # Initialize true_yaw as the same as the initial yaw
which_obj = 0  # Flag to track which object is being followed

# Function to handle the end of the parking process
def parking_end():
    global direction, yaw, true_yaw
    motor.go(130)  # Move the motor forward at speed 130
    while lidar.get(90) > 300:  # Check LIDAR data at 90 degrees (front)
        yaw = gyro.get_yaw()  # Get the current yaw from the gyroscope
        result = get_yaw_diff(true_yaw, yaw)  # Calculate the difference between true_yaw and current yaw
        result = clamp(result, -75, 75)  # Clamp the result within the steering limits
        result = map_range(result, -75, 75, -75, 75)  # Map the result to the steering range
        steer(servo, result)  # Adjust the steering to the calculated value
    motor.go(-130)  # Move the motor backward after parking
    print("first step done")
    if direction == 1:  # If the direction is 1 (left)
        true_yaw -= 90  # Adjust the true yaw by 90 degrees
        true_yaw += 360  # Add 360 to handle negative values
        true_yaw %= 360  # Ensure true_yaw stays within 0-360 degrees
    else:  # If the direction is not 1, assume it's the opposite direction (right)
        true_yaw += 90  # Adjust the true yaw by 90 degrees
        true_yaw += 360  # Add 360 to handle negative values
        true_yaw %= 360  # Ensure true_yaw stays within 0-360 degrees
        
    print(f"ya: {yaw}, true_yaw:{true_yaw}, diff:{abs(get_yaw_diff(true_yaw, yaw))}")  # Print the yaw values and their difference
    while abs(get_yaw_diff(true_yaw, yaw)) >= 7:  # If yaw difference is greater than 7 degrees
        yaw = gyro.get_yaw()  # Get the current yaw from the gyroscope
        result = get_yaw_diff(true_yaw, yaw)  # Calculate the yaw difference
        result = clamp(result, -75, 75)  # Clamp the result within the steering limits
        result = -map_range(result, -75, 75, -75, 75)  # Map the result to the steering range and invert it
        steer(servo, result)  # Adjust the steering to the calculated value
        print(f"restult = {result}")  # Print the steering result
    motor.go(130)  # Move the motor forward at speed 130
    while lidar.get(90) > 600:  # Keep moving until the LIDAR detects a distance greater than 600
        yaw = gyro.get_yaw()  # Get the current yaw from the gyroscope
        result = get_yaw_diff(true_yaw, yaw)  # Calculate the yaw difference
        result = map_range(result, -20, 20, -75, 75)  # Map the result to the steering range
        steer(servo, result)  # Adjust the steering to the calculated value
    if direction == 1:  # If the direction is 1 (left)
        true_yaw -= 90  # Adjust the true yaw by 90 degrees
        true_yaw += 360  # Add 360 to handle negative values
        true_yaw %= 360  # Ensure true_yaw stays within 0-360 degrees
    else:  # If the direction is not 1, assume it's the opposite direction (right)
        true_yaw += 90  # Adjust the true yaw by 90 degrees
        true_yaw += 360  # Add 360 to handle negative values
        true_yaw %= 360  # Ensure true_yaw stays within 0-360 degrees
    while abs(get_yaw_diff(true_yaw, yaw)) >= 20:  # If yaw difference is greater than 20 degrees
        yaw = gyro.get_yaw()  # Get the current yaw from the gyroscope
        result = get_yaw_diff(true_yaw, yaw)  # Calculate the yaw difference
        result = clamp(result, -75, 75)  # Clamp the result within the steering limits
        result = map_range(result, -75, 75, -75, 75)  # Map the result to the steering range
        steer(servo, result)  # Adjust the steering to the calculated value
        print(f"restult = {result}")  # Print the steering result

    while True:  # Start the continuous loop
        if direction == 2:  # If direction is 2 (right wall)
            rwall = lidar.get(180)  # Get LIDAR reading at 180 degrees (right wall)
            steering_value = map_range(rwall, 300, 500, -65, 65)  # Map the LIDAR reading to steering value
            steer(servo, steering_value)  # Adjust the steering to the calculated value
            print("following right wall")  # Print that the robot is following the right wall
            yaw = gyro.get_yaw()  # Get the current yaw from the gyroscope
        elif direction == 1:  # If direction is 1 (left wall)
            rwall = lidar.get(0)  # Get LIDAR reading at 0 degrees (left wall)
            steering_value = -map_range(rwall, 300, 500, -65, 65)  # Map the LIDAR reading to steering value (inverted)
            steer(servo, steering_value)  # Adjust the steering to the calculated value
            print("following left wall")  # Print that the robot is following the left wall
        if abs(get_yaw_diff(true_yaw, yaw)) < 5:  # If yaw difference is less than 5 degrees
            break  # Break the loop when the yaw difference is small enough
    parking_timer = 1000  # Set parking timer to 1000
    while True:  # Start the continuous loop
        ret, frame9 = cam.read()  # Read a frame from the camera
        if not ret:  # If frame is not successfully captured
            print("? Failed to grab frame.")  # Print an error message
            break  # Exit the loop if the frame capture fails
        frame9 = get_middle_frame(frame9)  # Get the middle portion of the frame
        cv.imshow("parking", frame9)  # Show the frame in the "parking" window
        hisab = getContours(frame9, 4, object_colors[4])  # Get contours for the frame with a specific color
        yaw = gyro.get_yaw()  # Get the current yaw from the gyroscope
        result = get_yaw_diff(true_yaw, yaw)  # Calculate the yaw difference
        result = clamp(result, -75, 75)  # Clamp the result within the steering limits
        result = map_range(result, -30, 30, -75, 75)  # Map the result to the steering range
        steer(servo, result)  # Adjust the steering to the calculated value
        if len(hisab) == 0:  # If no contours are found
            break  # Exit the loop if no objects are detected

    motor.stop()  # Stop the motor after parking is complete
    time.sleep(30)  # Wait for 30 seconds before exiting
    exit()  # Exit the program

def last_parking():
    global direction, yaw, true_yaw
    # This function is meant for handling last parking actions, but it is not defined yet

def start_from_parking(d):
    global yaw, true_yaw

    motor.go(-60)  # Move the motor backward at speed -60
    while lidar.get(270) > 160:  # Continue moving until LIDAR detects a distance less than 160 at 270 degrees (back)
        print(f"backwall={lidar.get(270)}")  # Print the back wall distance
    motor.stop()  # Stop the motor

    if d == 'L':  # If direction is left
        steer(servo, 75)  # Steer the robot left
        motor.go(100)  # Move the motor forward at speed 100
        while get_yaw_diff(true_yaw, yaw) > -30:  # If yaw difference is greater than -30 degrees
            yaw = gyro.get_yaw()  # Get the current yaw from the gyroscope
        while get_yaw_diff(true_yaw, yaw) > -60:  # If yaw difference is greater than -60 degrees
            yaw = gyro.get_yaw()  # Get the current yaw from the gyroscope
            print(f"true_yaw = {true_yaw}, yaw = {yaw}")  # Print the yaw values
    else:  # If direction is not left (right direction)
        steer(servo, -75)  # Steer the robot right
        motor.go(100)  # Move the motor forward at speed 100
        while get_yaw_diff(true_yaw, yaw) < 30:  # If yaw difference is less than 30 degrees
            yaw = gyro.get_yaw()  # Get the current yaw from the gyroscope
        while get_yaw_diff(true_yaw, yaw) < 60:  # If yaw difference is less than 60 degrees
            yaw = gyro.get_yaw()  # Get the current yaw from the gyroscope
    steer(servo, 0)  # Set the steering to 0 (straight)
    motor.go(speed)  # Move the motor forward at the set speed
    time.sleep(0.25)  # Wait for 0.25 seconds

prev_btn_state = 1  # Initialize the previous button state
btn_cnt = 0  # Initialize the button press count
status = 0  # Initialize the robot status
yaw_cnt = 0  # Initialize the yaw counter
pi.write(LED_PIN, 1)  # Turn the LED on
parking = 0  # Initialize parking flag
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

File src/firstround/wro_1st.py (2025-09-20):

import time
from utility import clamp, map_range, steer  # Import utility functions for clamping, mapping values, and steering the servo
from line_checks import coords, linearity, are_perpendicular, get_intersection  # Import geometric functions for line checks and intersections
from servo import Servo  # Import Servo control class
from lidar_reader import LidarReader  # Import LidarReader for reading Lidar sensor data
from motor import Motor  # Import Motor control class
import numpy as np  # Import numpy for array handling and calculations
from scipy.stats import linregress, false_discovery_control  # Import statistical functions (though only `linregress` is used)
from shapely.geometry import Point, Polygon  # Import for geometric operations and handling polygons
import pigpio  # Import the pigpio library for GPIO control

pi = pigpio.pi()  # Initialize pigpio instance for controlling GPIO pins
lidar = LidarReader(path="/home/wro/rplidar_sdk/output/Linux/Release/ultra_simple")  # Initialize LidarReader
servo = Servo(4)  # Initialize Servo on pin 4
motor = Motor(pi)  # Initialize motor with pigpio instance

# Constants for wall distances and directions
rwall = 0
lwall = 0
direction = 0
err = 22  # Error margin for distance calculations
f = 0
checker = 13  # Angle check increment
last_time = -100  # Variable to store the last time for periodic actions

# Define angle groups for Lidar data
angle_groups = {
    "front": [356, 357, 358, 359, 0, 1, 2, 3, 4],
    "right": [86, 88, 90, 92, 94],
    "left": [266, 268, 270, 272, 274]
}

# Main loop that continues until both right and left walls are detected
while True:
    if rwall and lwall:
        break
    rwall = lidar.get(90)  # Get right wall distance from Lidar
    lwall = lidar.get(270)  # Get left wall distance from Lidar

# Decide which wall to follow based on which is closer
if rwall <= lwall:
    follow_ang = 65  # Follow the right wall
    corner_ang = 270  # Corner angle for turning
    print("following right wall")
elif lwall < rwall:
    follow_ang = 295  # Follow the left wall
    corner_ang = 90  # Corner angle for turning
    print("following left wall")

corner = 0  # Initialize corner counter
fwall_init = lidar.get(0)  # Get initial front distance
center_dist = lidar.get(follow_ang)  # Get center distance based on follow angle
min_dist = 100  # Minimum distance threshold
max_dist = (2 * center_dist) - min_dist  # Maximum distance threshold
print(f"rwall={rwall} lwall={lwall} center={center_dist} max_dist={max_dist}")
time.sleep(3)
motor.forward(255)  # Move forward at maximum speed

# Function to get Lidar data for specified angles
def get_lidar_points(angles):
    points = []
    for angle in angles:
        r = lidar.get(angle)
        x, y = coords(r, angle)  # Convert polar coordinates to Cartesian
        points.append([x, y])
    return np.array(points)

# Main loop for Lidar-based navigation
try:
    while True:
        print(direction)
        if direction == 0:
            num_groups = len(angle_groups)
            slopes = [None] * num_groups  # Initialize list for slopes (None for vertical lines)
            intercepts = [None] * num_groups
            R2_values = [None] * num_groups
            f = 1  # Flag for indicating if lines are valid
            cnt = 0
            print("start")
            for name, angs in angle_groups.items():
                pts = get_lidar_points(angs)  # Get points for the current group of angles
                is_line, slope, intercept, r2 = linearity(pts)  # Check if points form a line
                slopes[cnt] = slope
                intercepts[cnt] = intercept
                R2_values[cnt] = r2
                if not is_line:
                    f = 0  # If any group is not a line, set flag to 0
                cnt += 1
                if name == "left":
                    print(f, slope, intercept, pts)
                    for angee in angs:
                        print(lidar.get(angee))
                    print()

            # Check for perpendicular lines
            if f == 1:
                if not are_perpendicular(slopes[0], slopes[1]):
                    print("rejected Line")
                    f = 0
                if not are_perpendicular(slopes[0], slopes[2]):
                    print("rejected Line")
                    f = 0

            #

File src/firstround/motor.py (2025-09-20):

from utility import map_range, clamp  # Import utility functions for mapping and clamping values
import pigpio  # Import the pigpio library for controlling GPIO pins

class Motor:
    def __init__(self, pi, forward_pin=12, reverse_pin=18, freq=1000):
        """
        Motor class to control a motor with forward and reverse functions using GPIO pins.

        pi          = pigpio.pi() instance (already connected to the Raspberry Pi)
        forward_pin = GPIO pin for forward direction (default: 12)
        reverse_pin = GPIO pin for reverse direction (default: 18)
        freq        = PWM frequency for controlling motor speed (default: 1000 Hz)
        """
        self.pi = pi  # Store the pigpio instance
        self.forward_pin = forward_pin  # Set GPIO pin for forward direction
        self.reverse_pin = reverse_pin  # Set GPIO pin for reverse direction
        self.freq = freq  # Set PWM frequency

        # Setup GPIO pins as OUTPUT
        self.pi.set_mode(self.forward_pin, pigpio.OUTPUT)
        self.pi.set_mode(self.reverse_pin, pigpio.OUTPUT)

        # Ensure motor is stopped initially
        self.stop()

    def forward(self, speed=255):
        """
        Run motor in the forward direction with the specified speed.

        speed = PWM duty cycle (0 to 255)
        """
        speed = clamp(speed, 0, 255)  # Ensure speed is within range (0 to 255)
        self.pi.set_PWM_frequency(self.forward_pin, self.freq)  # Set PWM frequency for forward pin
        self.pi.set_PWM_dutycycle(self.forward_pin, speed)  # Set PWM duty cycle for forward direction
        self.pi.write(self.reverse_pin, 0)  # Ensure reverse direction is off

    def reverse(self, speed=255):
        """
        Run motor in the reverse direction with the specified speed.

        speed = PWM duty cycle (0 to 255)
        """
        speed = clamp(speed, 0, 255)  # Ensure speed is within range (0 to 255)
        self.pi.set_PWM_frequency(self.reverse_pin, self.freq)  # Set PWM frequency for reverse pin
        self.pi.set_PWM_dutycycle(self.reverse_pin, speed)  # Set PWM duty cycle for reverse direction
        self.pi.write(self.forward_pin, 0)  # Ensure forward direction is off

    def stop(self):
        """
        Stop the motor completely by turning off both forward and reverse directions.
        """
        self.pi.set_PWM_dutycycle(self.forward_pin, 0)  # Set forward pin PWM duty cycle to 0
        self.pi.set_PWM_dutycycle(self.reverse_pin, 0)  # Set reverse pin PWM duty cycle to 0
